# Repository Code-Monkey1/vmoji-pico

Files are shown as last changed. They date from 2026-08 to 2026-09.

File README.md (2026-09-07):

# vmoji-pico
Volumetric Display for the Raspberry Pi Pico (RP2040).

Mechanical CAD (OpenSCAD dual-motor drive): [3D/README.md](3D/README.md).

## Firmware host tests

Logic tests run on the PC (no Pico SDK / board required):

```bash
cmake -S tests/firmware -B build-host-tests
cmake --build build-host-tests
ctest --test-dir build-host-tests --output-on-failure
```

Manual sim/POV bring-up steps: [tests/firmware/acceptance/BRINGUP.md](tests/firmware/acceptance/BRINGUP.md).

## Telemetry dashboard

The firmware streams binary telemetry at 10 Hz - measured scan rate, per-scan
jitter, die temperature and the live framebuffer - to a PySide6 desktop
dashboard that plots it in real time, logs it, and can replay a recording.

See [tools/dashboard/README.md](tools/dashboard/README.md).

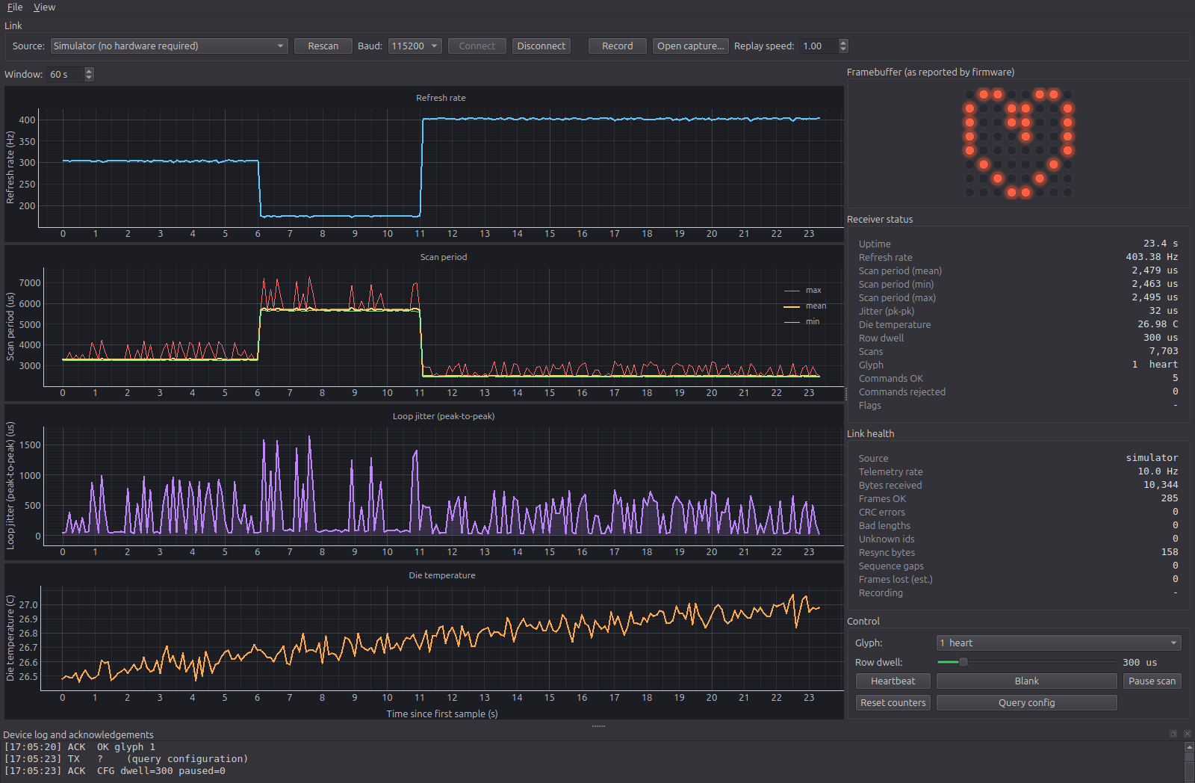
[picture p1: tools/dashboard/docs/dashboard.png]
vmoji telemetry dashboard


The dashboard also runs against a built-in simulator, so no hardware is needed to
try it:

```bash
cd tools/dashboard
python3 -m venv .venv && .venv/bin/pip install -r requirements.txt
.venv/bin/python app.py
```

## Dev Env Setup

We use the "Raspberry Pi Pico Project" extension in VS Code with a Linux PC.  
With it, you can prepare the environment (install the "pico-sdk" SDK locally).  

This [PDF guide](https://pip-assets.raspberrypi.com/categories/610-raspberry-pi-pico/documents/RP-008276-DS-1-getting-started-with-pico.pdf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) explains very well what to do.

To let it run properly the commands it needs without any permission issue (without needing to always write `sudo`),
the `/etc/udev/rules.d/99-picotool.rules` file was created with the following content:
`SUBSYSTEM=="usb", ATTR{idVendor}=="2e8a", MODE="0666"`  

After, reload the rules:  
`sudo udevadm control --reload-rules`  
`sudo udevadm trigger`  

For cross-debugging, make sure you installed the appropriate tools:

`sudo apt update`  
`sudo apt install gdb-multiarch binutils-multiarch gcc-arm-none-eabi`  

## Quick Start (VS Code)

### Building
From the extension, you can click "Compile Project".  

### Flashing by Copy/Paste
If not in bootloader mode already, reconnect the Raspberry Pi Pico while pressing down on the bootloader button.  
You should now see it as a "USB device" in your file explorer.  
Copy/paste the build .uf2 output file into that USB device to flash the device.

The device will restart automatically and run the program you flashed.

### Flashing via SWD
Using the debug probe, you can flash quickly via SWD. See the guide for detailed instructions.  
This way you don't need to unplug and re-plug the raspberry pi each time, which is convenient.

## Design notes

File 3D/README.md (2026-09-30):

# vmoji mechanical (OpenSCAD) — v2

Coil-safe dual-motor gear drive for the volumetric display. The rotor turns on
**two 608ZZ**: the bottom one clamped on an M8 stud in the base, the top one hanging
under the TX deck, `vm_top_bearing_coil_clear` (10 mm) below the TX coil. A printed
plastic rotor runs through the TX–RX gap. Preview the full stack with
[`assembly-preview.scad`](assembly-preview.scad) (F5; optional Animate, `section` toggle)
and check it with [`check-collisions.sh`](check-collisions.sh).

Defaults live in [`vmoji-mech-params.scad`](vmoji-mech-params.scad). Every
print file includes that before `motor-base-common.scad`.

## BOM

| Qty | Part | Notes |
|-----|---|---|
| 2 | 608ZZ bearing | Bottom (base pocket) + top (TX deck hanging pocket). |
| 1 | M8×25 DIN 912 / ISO 4762 SHCS | Stud through the bottom 608. Head Ø13 × 8 mm, hex key 6 mm. |
| 1 | M8 hex nut | Clamps the bottom 608 inner race; the rotor's hex socket drops over it. |
| 2 | Printed race spacers | `bearing-spacer.scad`, 100 % infill. Head and nut are wider than the inner race; spacers keep them off the shields. |
| 8 | M3×6 heat-set inserts (Ø4.2) | 4 column spigots (TX deck bolts) + 4 lid posts. |
| 4 | M3×4 heat-set inserts (Ø4.2) | Rotor head PCB bosses. |
| 4 | M3×8 screws | TX deck → columns. |
| 4 | M3×8 screws | Lid → posts. |
| 4 | M3×6 screws | PCB → head. |
| 1 | M3×10 SHCS | Head center screw, self-taps into the shaft top. |
| 0–6 | M3 nuts | Counterweights (glued into the head pockets). |
| 2 | RF-300C-class motors | Ø24 × 12, Ø2.0 shaft sticking out 4–5 mm (`vm_motor_shaft_len`). |
| 1 | IR LED + 1 phototransistor | 5 mm by default (`vm_ir_d`, `vm_ir_flange_d`, `vm_ir_len` for 3 mm parts). |
| 1 | 40 × 60 mm proto PCB | 4 M3 corner holes; set `vm_pcb_hole_dx/dy` to your board (placeholder 52 × 32). |

**Buy the stud screw:** [M8 hex-socket assortment (16/20/25/30)](https://www.amazon.ca/gp/product/B0GPXBPR31).
Use a **25 mm** screw: its tip sticks ~8 mm above the nut and centers the rotor.

These SHCS are typically fully threaded. The thread crest sits inside the 608 bore;
that's fine because the inner race is clamped by the stud, not sliding on it.

## Coil-safe rules

- Face gap TX top → RX bottom: **8–20 mm** (`vm_coil_gap`, prefer 8).
- The M8 stud tip stays below the TX deck (`vm_assert_coil_gap_metal_free`).
- The top 608 stays `vm_top_bearing_coil_clear` below the TX coil (default 10 mm, hard floor 4 mm).
- No set-screw into the plastic rotor, no threads in plastic under load (hex + key drives).

World **z=0** is the structural floor / bottom 608 bottom. Table contact is at
`-vm_skirt_h` (~10.5 mm) so the SHCS head sits above the table without feet.

## Spin direction and gears

Single helical 14T / 28T, m1.25, 25°. Herringbone can't be meshed by dropping the rotor in;
helical can (the unpowered pinions turn as the teeth slide in). Mating helical gears need
**opposite** helix angles (the v1 files used the same sign for both).

`vm_rotor_dir = -1`: the rotor spins **clockwise viewed from the top**, the pinions
counter-clockwise. The hands are chosen so the pinions are pushed **down** toward the
motors (keeps the press-fits seated) and the rotor slightly up (far less than its weight).
If the rotor spins the other way, swap the motor leads (both motors in parallel, same
polarity). If you'd rather have CCW, set `vm_rotor_dir = 1` and reprint pinions + rotor.

## Material (PLA)

Everything prints in PLA. PLA softens around 55–60 °C and creeps under constant load, so:

- Don't run the motors hot; a warm can slowly loosens the pinion press-fit and crush ribs.
  If a pinion slips, put a drop of **CA glue** (cyanoacrylate, "super glue") on the shaft and press it back on.
- Keep the TX coil power reasonable; the deck holds the top 608 pocket right under it.
- Race spacers: 100 % infill. Tighten the M8 stud firmly but don't crank it.

## Print orientation

| Part | File | Orientation / tips |
|---|---|---|
| Motor base | `motor-base.scad` | Skirt down on bed. Supports from the build plate inside the skirt (floor + well ledges bridge the hollow). |
| TX deck | `motor-tx-deck.scad` | **Upside down** (coil face on bed): no overhangs, the bearing pocket opens upward. |
| Rotor shaft | `rotor-shaft.scad` | Gear face down, axis vertical. Brim; 4+ perimeters (thin shaft). |
| Rotor head | `rotor-head.scad` | Underside (RX coil rebate) on bed. |
| Pinions (×2) | `motor-pinion.scad` | Underside down; good cooling. |
| Lid | `motor-base-lid.scad` | Top face on bed (lip up). |
| Race spacers (×2) | `bearing-spacer.scad` | Flat, 100 % infill. |
| Fit coupons | `fit-test.scad` | Flat. Pick one with `coupon`, or `all`. |

## Assembly order

Every step is top-down.

1. Print the fit coupons first and tune (see **Fit tuning**).
2. Heat-set the inserts while the parts are bare: M3×6 into the 4 column spigots and the
   4 lid posts, M3×4 into the 4 head bosses (the iron clearance above each is checked).
3. **Bottom stud:** press a 608 into the base pocket (outer race on the z=0 lip). From below:
   spacer, then M8×25 up through the bearing. On top: spacer, then the M8 nut. Tighten (6 mm key
   below, 13 mm wrench above). The stud + nut must now spin freely with the inner race.
4. **Motors:** solder leads, thread them down through the well ledge hole into the skirt and
   up through the box floor slots. Press each motor into its crush-rib well until it sits on the ledge.
5. **Pinions:** put a 0.5 mm shim (`vm_pinion_face_gap`, e.g. two business cards) on the motor
   face and press the pinion down onto it; the ledge takes the force. Remove the shim.
6. **Rotor:** lower it onto the stud. The tip enters the centering bore, the hex socket drops
   over the nut (turn slightly), and the helical teeth twist into mesh with the pinions.
7. **TX deck:** glue the TX coil into the rebate (leads in the groove toward the box), push the
   IR LED in from below (flange against the step, dab of glue), and press the top 608 into the
   hanging pocket from below until it stops on the lip.
8. Lower the deck over the rotor: the bearing slides onto the journal and the column spigots
   drop into the deck recesses. Bolt it down with 4× M3×8. Route TX + IR leads into the box
   through the notch at the top of its wall.
9. **Head:** hot-glue the RX coil into the rebate (glue into the three notches), leads up
   through the lead hole. Drop the phototransistor into its hole from above (dome down,
   flange on the boss).
10. Slide the head onto the double-D key and drive the M3×10 center screw (self-taps; snug only).
11. Bolt the PCB with 4× M3×6; solder the RX leads and the phototransistor.
12. Screw the lid on (4× M3×8).
13. Balance (below).

## Balancing

The LED matrix sits off-axis, so the rotor is heavy on one side. At ~1000 RPM a few grams
off-center shakes the whole thing.

1. Take the base off the table and lay it on its side (rotor axis horizontal). Unpowered.
2. Let the rotor come to rest; the heavy side ends up at the bottom.
3. Glue M3 nuts into the head pockets on the **top** (light) side. Repeat until the rotor stays
   wherever you leave it.
4. Spin up slowly and feel for vibration; nudge weights if needed.

## Fit tuning

Print `fit-test.scad`, try each coupon on the real part, then copy the winner here.

| Param | Default | Coupon | Role |
|---|---|---|---|
| `vm_motor_shaft_d` | 1.9 | `motor_shaft` | Pinion press bore on the Ø2 shaft (proven; change only if needed). |
| `vm_top_journal_d` | 7.95 | `journal` | Journal: snug slide into the top 608 inner race. |
| `vm_bearing_fit` | 0.15 | `bearing_od` | 608 OD pockets (plus `$slop`). |
| `vm_nut_socket_extra` | 0.4 | `nut_socket` | Hex socket over the M8 nut (loose: drive only). |
| `vm_tip_bore_extra` | 0.15 | `tip_bore` | Snug bore on the M8 tip (this centers the rotor). |
| `vm_key_fit` | 0.25 | `key` | Head socket on the double-D key. |
| `vm_well_rib_interf` | 0.15 | `well` | Crush-rib grip on the motor can. |
| `vm_insert_hole_d` | 4.0 | `insert` | Heat-set pilot (plus `$slop`). |
| `vm_locate_fit` / `vm_locate_loose` | 0.15 / 0.8 | `locate` | Deck recesses on the column spigots (diagonal pair tight). |
| `vm_ir_hole_extra` | 0.3 | `ir` | IR LED / phototransistor holes. |
| `$slop` | 0.2 | — | Global print clearance (clearance holes). |

The display ghost in the preview (60×40 PCB + 8×8 matrix) is approximate; the swept
volume check uses its envelope.

## Collision and assembly checks

- **Analytic asserts** (`vm_assert_layout()` in `motor-base-common.scad`) run in every file:
  box ↔ deck gap (`vm_porch_gap`, 3 mm), coil gaps, bearing-to-coil distance, metal below the
  coil zone, well ↔ bearing walls, gear ↔ column / well clearance, IR beam gap, insert boss walls, and more.
- **Geometric checks:** `./check-collisions.sh` intersects every part pair as assembled
  (spinning parts as swept envelopes) plus a soldering-iron cylinder above every insert, and
  fails on any real overlap. Takes ~5 min on OpenSCAD 2021; newer builds are faster with
  `OPENSCAD_ARGS="--enable=manifold"`. Run a subset with `./check-collisions.sh base_deck coils`.

## File map

| File | Role |
|---|---|
| `vmoji-mech-params.scad` | Shared dims, Z stack |
| `motor-base-common.scad` | Clearances, gear math, layout, envelopes, `vm_assert_layout()` |
| `vmoji-assembly.scad` | World placement of every part + hardware ghosts |
| `assembly-preview.scad` | Full F5 assembly + animation + section |
| `collision-check.scad` / `check-collisions.sh` | Pairwise collision + iron-access checks |
| `motor-base.scad` | Floor, skirt, bottom 608 pocket, crush-rib wells, columns, box |
| `motor-base-lid.scad` | Box lid |
| `motor-tx-deck.scad` | TX plate + hanging top 608 pocket + IR emitter |
| `motor-pinion.scad` | 14T helical, press-fit |
| `rotor-shaft.scad` | Rotor: 28T helical gear + nut socket + journal + key |
| `rotor-head.scad` | RX coil holder + PCB mount + counterweights + IR receiver |
| `bearing-spacer.scad` | 608 inner-race spacer |
| `fit-test.scad` | Fit coupons |
| `archive/` | v1 parts (driven shaft/gear, shaft collar, collets). Kept for reference; their includes no longer resolve from that folder. |

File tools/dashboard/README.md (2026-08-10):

# vmoji telemetry dashboard

A real-time instrumentation dashboard for the vmoji volumetric display, built to
debug the RP2040 firmware's scan loop from a PC over USB or UART.

The dashboard streaming from the simulator

The screenshot shows a live session. The two steps in the refresh-rate trace are
row-dwell changes sent from the control panel: raising the dwell from 400 us to
700 us drops the scan rate from ~400 Hz to ~190 Hz, and the scan-period trace
moves inversely. That correlation is the entire point of the tool - it turns "the
display looks dim" into a number you can act on.

## Why this exists

The display is a real-time system. An 8x8 matrix multiplexed one row at a time
only looks like an image because the scan loop is fast and *regular*; if the loop
loses time to command handling or a slow serial write, the result is visible
flicker and uneven brightness. None of that is diagnosable from the firmware
side, because the act of printing debug output is itself the thing that perturbs
the timing.

So the firmware measures its own scan interval, accumulates min/mean/max over a
100 ms window, and ships that as a compact binary frame. The host does the
plotting, the storage and the interpretation.

## Architecture

```
 ┌─────────────┐
 │ SerialSource│──┐
 │ SimSource   │──┼──▶ ReaderWorker ──queued signal──▶ TelemetryModel
 │ ReplaySource│──┘   (on a QThread)                  (bounded deques)
 └─────────────┘            │                               │
                            ▼                    QTimer @ 30 Hz
                      CaptureWriter                         │
                       (.vmc file) ─────────────────────▶  views
                                    replay
```

Four decisions carry the design:

**The reader thread never touches a widget.** `ReaderWorker` is a plain `QObject`
moved onto a `QThread`. It owns the source and the parser, and it communicates
only by emitting signals. Because the connections are made from the GUI thread,
Qt delivers them as queued connections and marshals the payload onto the event
loop. Blocking reads stay off the event loop, so the UI never freezes, and there
is not a single explicit lock in the GUI path.

**The data rate and the frame rate are independent.** Messages are appended to
the model on arrival; a `QTimer` repaints at 30 Hz regardless. Nobody can see
faster than that, and coupling repaints to arrivals is the standard way these
tools fall over when the data rate rises. The same UI would work unchanged at
10 kHz.

**Every buffer is bounded.** Series are `deque(maxlen=12000)` - 20 minutes at
10 Hz - and the log view is capped at 2000 blocks. A monitoring tool gets left
running for days, and an unbounded list is a memory leak with a good excuse.
pyqtgraph is configured with `setDownsampling(auto=True, mode='peak')` and
`setClipToView(True)`, so only the visible, decimated samples are rasterised.

**The source is swappable.** The app runs identically off a live board, a
simulator, or a recorded capture. That means it can be developed and demonstrated
with no hardware, and it means a field capture can be re-run through the exact
production parser.

## The wire protocol

Defined once, in [`../../vmoji/telemetry_frame.h`](../../vmoji/telemetry_frame.h),
and shaped after GNSS receiver binary protocols such as u-blox UBX and RTCM 3.x:

```
offset  size  field
0       2     sync word 0xAA 0x55
2       2     payload length, u16 little-endian
4       1     message id
5       1     sequence number (wraps at 256)
6       N     payload
6+N     2     CRC-16/CCITT-FALSE over offsets [2, 6+N)
```

Each element earns its place:

- **Sync word** so a listener can lock onto a stream it joined mid-frame.
- **Explicit length** so the reader knows where the message ends without escaping
  or delimiters, which is what lets the payload contain arbitrary bytes.
- **Sequence number** so the host can *detect loss it cannot prevent*. A gap is
  reported rather than silently interpolated.
- **CRC** so corrupted frames are dropped instead of plotted. It covers the length
  and id but not the sync word, so a sync word occurring inside payload data
  cannot produce a frame that also passes the CRC.

Messages: `Status` (0x01, 32-byte payload at 10 Hz), `FrameBuffer` (0x02, the 8x8
bitmap at 2 Hz), `Log` (0x03) and `Ack` (0x10), both ASCII.

`Status` carries uptime, total scan count, measured refresh rate in centi-hertz,
scan period min/mean/max, peak-to-peak jitter, RP2040 die temperature from the
on-chip sensor, accepted and rejected command counts, received byte count,
current row dwell, glyph id and status flags.

The flags are `ACTIVITY` (0x01, the activity pixel is lit), `OVERRUN` (0x02, the
UART receive ring dropped a byte), `PAUSED` (0x04, scanning suspended by
command) and `TX_DROP` (0x08, a telemetry frame was discarded because a link
could not keep up). `TX_DROP` reports a full transmit ring on the UART, or on
USB while a host is attached; bytes produced with no USB host attached are
discarded without raising it, so the flag stays meaningful on a UART-only
setup. A host that is attached but not draining its endpoint is the one gap:
the write gives up after `PICO_STDIO_USB_STDOUT_TIMEOUT_US` and the loss shows
as a gap in sequence numbers rather than as this flag.

A host that receives a `Status` payload *longer* than the 32
bytes it knows about decodes the prefix and ignores the rest, so newer firmware
can add fields without breaking an older dashboard.

### Why the uplink is ASCII

Commands stay line-oriented text (`S 2 3`, `G 4`, `D 900`, `B`, `P`, `Z`, `?`, `I`) so
the board can still be driven from `minicom` with no tooling at all during
bring-up. Framing and a CRC earn their keep on a 10 Hz downlink carrying packed
binary; they are pure overhead on six commands a minute typed by a human.

### Keeping two implementations honest

The protocol has a C++ implementation (firmware and host) and a Python one
(dashboard). Two implementations of one wire format drift apart unless something
forces them to agree, and a silent drift shows up weeks later as "the dashboard
is wrong."

So [`../protocol_selftest.cpp`](../protocol_selftest.cpp) emits reference vectors,
and `tests/test_protocol.py` pins them:

```bash
# From the repo root: the C++ side, including its own checks
g++ -std=c++17 -Wall -Wextra -I vmoji tools/protocol_selftest.cpp -o /tmp/selftest
/tmp/selftest
/tmp/selftest --vectors        # hex vectors consumed by the Python tests
```

The strongest of those tests asserts the Python encoder reproduces the C++ bytes
exactly.

## Running it

```bash
cd tools/dashboard
python3 -m venv .venv
.venv/bin/pip install -r requirements.txt

.venv/bin/python app.py                       # find a board; simulator only if none
.venv/bin/python app.py --sim                 # force the simulator
.venv/bin/python app.py --list-ports          # enumerate and rank serial ports
.venv/bin/python app.py --port /dev/ttyACM0   # a specific port, no searching
.venv/bin/python app.py --no-probe            # skip the confirm-a-frame check
.venv/bin/python app.py --replay session.vmc  # replay a capture
.venv/bin/python app.py --record out.vmc      # record from the start, no dialog
.venv/bin/python app.py --error-rate 0.05     # corrupt 5% of frames on purpose
```

### Finding the board

With no arguments the dashboard looks for real hardware and only falls back to
the simulator if there is none. Ports are ranked by USB id - the Pico's own CDC
interface (`2e8a:000a`) first, then a Debug Probe's UART bridge (`2e8a:000c`),
then anything else - and the chosen port must produce one CRC-valid frame before
the dashboard commits to it. A matching USB id only proves a Pico is plugged in,
not that it is running this firmware, so the frame is the part that counts.

The simulator is deliberately convincing, which makes it dangerous in front of an
audience. It is therefore always last in the source list, never auto-selected,
and while it is running the window wears a **SIMULATION** banner and a title-bar
marker. When a real board is connected the Link panel shows its unique chip id,
so "is this actually the hardware?" has a visible answer at all times.

If a live link drops - a bumped USB cable is the usual cause - the dashboard
reconnects on its own with a bounded backoff rather than ending the session, and
it re-scans for ports every two seconds so a board plugged in later shows up
without pressing Rescan.

### Replaying a capture

A recording is the one source you can actually navigate, so it gets a transport
bar: play/pause, restart, loop, a seek slider with elapsed and total time, and a
speed control. Seeking cuts the byte stream mid-frame and the parser
resynchronises at the new position, which is the honest outcome of seeking a
byte stream and the same recovery path a noisy link exercises.

On Linux, PySide6 6.5+ needs `libxcb-cursor0` for the xcb platform plugin:

```bash
sudo apt install libxcb-cursor0
```

### Flashing the firmware

```bash
cd vmoji
export PICO_SDK_PATH=$HOME/.pico-sdk/sdk/2.3.0
export PATH="$HOME/.pico-sdk/toolchain/14_2_Rel1/bin:$PATH"
cmake -S . -B build -G Ninja -DCMAKE_BUILD_TYPE=Release
ninja -C build
# then copy build/vmoji.uf2 onto the board in BOOTSEL mode, or flash over SWD
```

The firmware sends telemetry on **both** USB CDC (`/dev/ttyACM0`) and UART0
(GP0 TX / GP1 RX at 115200 8N1), so either transport works.

On UART the very first bytes are an unframed ASCII banner, which doubles as a
permanent test that the parser can find its sync word in a stream that does not
start with one. USB behaves differently and it is worth knowing why: the CDC
stack discards everything written before a host opens the port, so a dashboard
attaching later never sees the banner and starts mid-stream instead. Board
identity therefore travels as a framed `Log` message rather than as banner text:

```
ID vmoji 1.1.0 sha=5ab4f62a board=E6614C775B59B537
```

The firmware repeats it every 10 s and on demand via the `I` command, so it
reaches a host regardless of when that host arrived. `board=` is the RP2040's
unique chip id, which is what lets the dashboard name the specific board on
screen - and what makes a live demo distinguishable from the simulator.

### Bring-up check

Run this before opening the GUI. If something is wrong - wrong port, wrong baud,
firmware not running, TX and RX swapped - it says so in one line, instead of
leaving you staring at an empty plot unsure whether the fault is in the firmware
or the dashboard:

```bash
.venv/bin/python verify_link.py --port /dev/ttyACM0
.venv/bin/python verify_link.py --port /dev/ttyACM0 --command "D 900"
.venv/bin/python verify_link.py                       # sanity-check the simulator
```

It checks the numbers, not just that bytes moved: telemetry arriving well under
10 Hz, a zero refresh rate, an implausible die temperature, a CRC error rate over
1%, or jitter exceeding the mean scan period each produce a specific warning. It
exits non-zero on failure, so it works in a script.

### Tests

```bash
cd tools/dashboard
.venv/bin/python -m pytest tests -q
```

86 tests, no hardware required.

The protocol tests cover the cross-language vectors, frames split byte-by-byte
across reads, resynchronisation past a boot banner, CRC rejection and recovery,
oversized length fields, sequence gaps and 8-bit wrap, unknown message ids, a
sync word embedded in a payload, buffer growth under pure noise, capture
round-tripping, and `SerialSource` driven over a pty so the real pyserial path is
exercised in both directions without a board attached.

The dashboard tests cover port ranking and the probe - including a pty that
emits unrelated chatter, which must *not* be mistaken for a board - replay
seeking, pausing and speed changes, a `Status` payload carrying extra trailing
fields from hypothetical newer firmware, and the window's minimum size. That last
one is a regression guard with a specific history: the minimum had reached
986x1186, which does not fit on a 1080p laptop. A minimum size grows one
innocuous widget at a time, so the only thing that keeps it down is a test that
fails when it grows.

`tests/test_panels.py` covers the logic that was lifted out of the window:
reconnect backoff and its ceiling, the countdown text, which readout values are
highlighted, and the `exhausted` question the reader asks every source. None of
it needs an event loop.

## Repository layout

| Path | Role |
|---|---|
| `vmoji/telemetry_frame.h` | C++17 framing, `constexpr` CRC table, packed payloads. Compiles for both the Pico and the host |
| `vmoji/telemetry_flags.h` | Status flag bits, plain C, the single definition all three languages read |
| `vmoji/telemetry.h` | `extern "C"` interface so the C sources can call the C++ emitter |
| `vmoji/telemetry.cpp` | The emitter: per-scan statistics, die temperature, frame output |
| `vmoji/main.c` | `main` and the scan loop, and nothing else |
| `vmoji/matrix.c` | Pin mapping, the multiplexed scan, glyphs, digits, activity pixel |
| `vmoji/uart_link.c` | UART0 bring-up, the RX ring and its interrupt handler, boot banner |
| `vmoji/commands.c` | Line assembly and the command dispatch table |
| `tools/protocol_selftest.cpp` | Host self-test and reference vector generator |
| `tools/dashboard/protocol.py` | Parser, messages, statistics, shared constants. Qt-free |
| `tools/dashboard/sources.py` | Serial, simulator, replay sources; capture format; source factory. Qt-free |
| `tools/dashboard/model.py` | Bounded time series. Qt-free |
| `tools/dashboard/panels.py` | What each readout row says, and when it is highlighted. Qt-free |
| `tools/dashboard/reconnect.py` | Retry target and bounded backoff. Qt-free |
| `tools/dashboard/reader.py` | `QThread` worker |
| `tools/dashboard/widgets.py` | LED matrix view, key/value panel |
| `tools/dashboard/main_window.py` | Layout, wiring, repaint loop |
| `tools/dashboard/app.py` | CLI entry point |

The Qt-free boundary is deliberate: the parser, the sources, the model, the
panel formatting and the reconnect policy are plain Python and testable with
plain pytest, and the Qt layer on top is thin. The firmware is split the same
way, one job per translation unit, so the timed scan loop can be read without
the command grammar in the way.

## Things worth knowing

- **The firmware measures, the host interprets.** The device reports its observed
  scan interval, not a nominal figure from a datasheet. When the two disagree,
  the observation is what matters.
- **The observed telemetry rate is displayed alongside the firmware's reported
  refresh rate.** Two independent numbers, useful precisely when they disagree,
  because that is how you tell a firmware stall from a link problem.
- **Error counters are always visible** and highlight when non-zero. A debug tool
  that cannot tell you the link is degrading is worse than no tool, because it
  invites you to trust the plot.
- **Captures store raw bytes, not decoded records.** A decoded log can only ever
  be as correct as the parser that wrote it. Raw bytes plus host timestamps mean
  you can fix the parser and re-run history - and the CRC failures and line noise
  are preserved, which is usually the interesting part of a bad field test.
- **`--error-rate` is a feature, not a debug leftover.** Being able to *show* that
  the parser rejects corrupted frames and resynchronises is more convincing than
  asserting it.
- **Measuring timing with a blocking write changes what you measure.** The
  emitter originally pushed each frame out with `putchar_raw` per byte plus a
  blocking `uart_write_blocking`, which stalled the scan loop for longer than a
  row dwell every reporting interval. The instrument was the largest source of
  the jitter it was reporting:

  | | peak-to-peak jitter | worst scan period |
  |---|---|---|
  | blocking write | 1444 us | 4700 us |
  | queued, drained by IRQ | 57 us | 3317 us |

  Frames now go into per-link ring buffers. UART0 drains under its transmit
  interrupt; USB drains in bounded batches from the main loop, as one
  `stdio_put_string` call for the whole chunk rather than one stdio round trip
  per byte. A frame that will not fit is dropped whole rather than truncated -
  half a frame just costs the host a resync - and the drop raises a `TX DROP`
  status flag, so the gap is visible instead of silent.

## Possible next steps

- TCP source, so a board on a bench elsewhere can be monitored over the network
  (the `Source` protocol already accommodates it).
- A correlation view: dwell setting against achieved rate and jitter.
- CSV/Parquet export of the decoded series for offline analysis.
- PyInstaller packaging with a GitHub Actions matrix over Windows and Linux.
- Move the parser hot loop into C++ via pybind11 if the frame rate ever justifies
  it, reusing `telemetry_frame.h` so there is still one definition of the format.

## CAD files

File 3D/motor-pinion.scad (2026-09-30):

// Motor pinion — single helical, plain press-fit on the Ø2 motor shaft (no slit clamp).
// Blind bore: the shaft is only ~4–5 mm long; the gear sits vm_pinion_face_gap above the
// motor face (press down onto a shim of that thickness). Underside relieved for the motor
// boss. Print underside down. If a pinion ever slips, a drop of CA glue fixes it.
include <BOSL2/std.scad>
include <BOSL2/screws.scad>
include <BOSL2/gears.scad>
include <vmoji-mech-params.scad>
include <motor-base-common.scad>


/* [Press-fit] */
// Bore extra depth past the shaft tip (shaft must not bottom out).
bore_extra_depth = 0.4; // [0:0.1:2]
boss_relief_extra = 0.6; // [0:0.1:2]


/* [Hidden] */
$fa = 2;
$fs = 0.25;
$slop = 0.2;
cut_overlap = 0.2;


module motor_pinion(
    shaft_d = vm_motor_shaft_d,
    shaft_len = vm_motor_shaft_len,
    face_gap = vm_pinion_face_gap,
    gear_thickness = vm_gear_thickness,
    bore_extra_depth = bore_extra_depth,
    boss_relief_extra = boss_relief_extra
) {
    eps = cut_overlap;
    bore_depth = shaft_len - face_gap + bore_extra_depth;
    relief_h = max(0, vm_motor_boss_h - face_gap) + 0.3;

    assert(bore_depth < gear_thickness - 1, "Pinion bore breaks through the top");
    assert(vm_motor_boss_d + boss_relief_extra < mb_gear_root_d(vm_pinion_teeth) - 2,
        "Motor boss relief too wide for the pinion root");

    // Local z=0 = pinion underside (world vm_gear_z0()).
    diff() {
        up(gear_thickness / 2)
            mb_helical_gear(
                teeth = vm_pinion_teeth,
                helical = vm_pinion_helical(),
                thickness = gear_thickness
            );

        tag("remove") {
            down(eps)
                cyl(d = shaft_d, h = bore_depth + eps, anchor = BOTTOM, chamfer1 = -0.3);
            down(eps)
                cyl(d = vm_motor_boss_d + boss_relief_extra, h = relief_h + eps, anchor = BOTTOM);
        }
    }
}


motor_pinion();

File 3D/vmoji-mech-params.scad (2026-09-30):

// Single source of mechanical defaults for the dual-motor gear drive (v2).
// Include this BEFORE motor-base-common.scad in every print / preview file.
//
// BOM (coil-safe):
//   - 2x 608ZZ: bottom one in the base (on the M8 stud), top one hanging under the TX deck,
//     kept vm_top_bearing_coil_clear below the TX coil.
//   - 1x M8x25 DIN 912 / ISO 4762 socket head cap screw + 1x M8 hex nut + 2x printed
//     race spacers (bearing-spacer.scad). The screw + nut clamp the bottom 608 inner race and
//     form a stud; the rotor's hex socket slips over the nut and its bore centers on the tip.
//   - M3 heat-set inserts (Ø4.2): M3x6 in column tops and lid posts, M3x4 in the rotor head.
//   - Printed plastic rotor (rotor-shaft.scad + rotor-head.scad) through the TX–RX gap.
//
// Buy: Amazon "M8 hex socket screw assortment" (16/20/25/30). Use a 25 mm screw for the stud.
// Kit head is Ø13 x 8 mm, hex key 6 mm. These SHCS are typically fully threaded — the thread
// crest runs inside the 608 bore; that is fine because the inner race is clamped, not sliding.
//
// Fit convention: `$slop` (global print clearance) is added to clearance holes. Press / snug
// fits use explicit absolute extras below (tune them with fit-test.scad, not $slop).

/* ---- Motor (RF-300C-class) ---- */
vm_motor_d = 24;
vm_motor_h = 12;
vm_motor_shaft_d = 1.9; // Proven pinion press-fit bore on the Ø2.0 shaft; do not change casually.
vm_motor_shaft_len = 4.5; // Shaft length above the motor face (measured 4–5 mm).
// Front bearing boss on the motor face; the pinion underside is relieved around it.
vm_motor_boss_d = 7;
vm_motor_boss_h = 1;
// Terminal tabs + wires exit the can bottom through this hole in the well ledge.
vm_motor_term_hole_d = 18;

/* ---- Crush-rib press-fit motor wells (no clamp screw) ---- */
vm_well_clear = 0.3; // Radial clearance between can and smooth bore.
vm_well_rib_n = 6;
vm_well_rib_w = 1.2;
vm_well_rib_interf = 0.15; // Radial interference of each rib tip on the can.
vm_well_wall = 2.5;
vm_well_ledge_h = 1.5; // Floor ring under the can.
vm_well_rim_drop = 1.5; // Well rim sits this far below the can top.
vm_well_leadin = 0.8; // Chamfer at the rim for easy insertion.

/* ---- Gear train (2:1 single helical) ---- */
// Herringbone cannot be meshed by axial assembly; single helical can (the unpowered
// pinions rotate while the rotor drops in). Axial thrust is negligible at these torques.
vm_gear_mod = 1.25;
vm_pinion_teeth = 14;
vm_driven_teeth = 28;
vm_gear_helical = 25; // Magnitude only; hands are derived from vm_rotor_dir below.
vm_gear_backlash = 0.3;
vm_gear_thickness = 8; // Face width (pinion only grips the 4–5 mm motor shaft).
vm_gear_pressure_angle = 20;
vm_gear_slices = 8;
// Air gap between pinion underside and motor face (press the pinion down onto a shim).
vm_pinion_face_gap = 0.5;
// Rotor spin: -1 = clockwise viewed from the top, +1 = counter-clockwise.
// Hands are picked so the helix pushes the rotor UP (well below its weight) and the
// pinions DOWN toward the motors, which keeps the pinion press-fits seated.
vm_rotor_dir = -1; // [-1, 1]
function vm_driven_helical() = vm_rotor_dir * vm_gear_helical;
function vm_pinion_helical() = -vm_driven_helical();

/* ---- 608ZZ (bottom in base + top under TX deck) ---- */
vm_bearing_id = 8;
vm_bearing_od = 22;
vm_bearing_h = 7;
vm_bearing_fit = 0.15;
vm_bearing_inner_race_od = 12; // Nothing clamped/rotating may touch the shields outside this.
// OD lip at z=0: outer race sits on the annulus; spacer + head pass through the hole.
vm_bearing_lip_id = 16.8;
// Top 608: lip above the outer race only (inner race + shaft pass through).
vm_top_bearing_lip_id = 19.5;
// Steel top bearing top face → TX coil bottom face. Hard floor asserted at 4 mm.
vm_top_bearing_coil_clear = 10; // [4:0.5:20]

/* ---- M8 stud (SHCS + race spacers + nut) ---- */
// DIN 912 / ISO 4762 M8: head Ø13 x 8. ISO 4032 M8 nut: 13 AF x 6.5.
vm_shcs_d = 8;
vm_shcs_len = 25;
vm_shcs_head_d = 13;
vm_shcs_head_h = 8;
vm_bolt_head_pocket_d = 14.5; // head + print clearance
vm_nut_af = 13;
vm_nut_h = 6.5;
// Printed spacer rings touch only the inner race (head and nut are wider than it).
vm_race_spacer_id = 8.4;
vm_race_spacer_od = 11.5;
vm_race_spacer_h = 1.5;
// Continuous printed skirt so the head sits above the table (no rubber feet).
// head 8 + spacer 1.5 + ~1 clearance under head.
vm_skirt_h = 10.5;
vm_skirt_wall = 3;

/* ---- Rotor shaft (plastic, integrated driven gear) ---- */
vm_rotor_bottom_gap = 0.5; // Rotor underside above the upper race spacer.
vm_nut_socket_extra = 0.4; // Across-flats clearance: hex only drives, it does not center.
vm_tip_bore_extra = 0.15; // Snug bore on the M8 tip crest: this centers the rotor.
vm_tip_bore_headroom = 0.5; // Above the screw tip.
vm_rotor_collar_d = 11; // Shoulder above the gear; < inner race OD so it never touches shields.
vm_rotor_collar_gap = 0.5; // Collar top → top 608 inner race (rotor captive, not over-constrained).
vm_top_journal_d = 7.95; // Snug slide into the top 608 inner race (tune with fit-test.scad).
vm_rotor_shaft_d = 7.7; // Above the journal: lets the top 608 slide down freely.
// Double-D key at the shaft top for the rotor head (plus one center M3 self-tapped).
vm_key_flat = 6.2; // Across flats.
vm_key_len = 7; // Socket depth in the head.
vm_key_fit = 0.25; // Diametral clearance of the head socket on the key.
vm_center_pilot_d = 2.5; // M3 self-tap pilot in the shaft top.
vm_center_pilot_depth = 10;

/* ---- Induction rings ---- */
vm_ring_id = 21.5;
vm_ring_od = 41;
vm_ring_h = 1.2;
vm_ring_fit = 0.6; // Diametral clearance of the ring rebates.
// Face-to-face air gap between TX top and RX bottom. Hardware needs 8–20 mm; prefer 8.
vm_coil_gap = 8; // [8:0.5:20]

/* ---- TX deck ---- */
vm_deck_plate_t = 3; // Plastic under the TX ring.
vm_ring_rebate_extra = 0.3; // Rebate depth beyond ring_h.
vm_deck_shaft_clear_d = 10;
vm_deck_boss_wall = 2.5; // Around the top 608 pocket.
vm_tx_wire_y = -12; // TX lead groove runs to the +X edge at this Y.
vm_tx_wire_w = 3;

/* ---- Rotor head (RX coil + PCB) ---- */
vm_rx_recess = 0.2; // RX copper face sits this far inside the head underside.
vm_head_over_coil = 3; // Plastic above the RX coil.
// The PCB-footprint plate runs from the head underside to the disk top (prints flat).
vm_head_hub_d = 14;
vm_head_ceiling_t = 1.5; // Socket ceiling under the center screw head.
vm_center_screw_head_h = 3; // M3 SHCS head sits on the hub, under the PCB.
vm_rx_wire_d = 3.5;
vm_rx_wire_angle = 90;
vm_glue_notch_n = 3;
vm_glue_notch_w = 3;
vm_glue_notch_d = 1.5;
// Counterweight pockets (M3 nuts, glued) to balance the off-axis LED matrix.
vm_cw_n = 6;
vm_cw_r = 15;
vm_cw_nut_af = 5.5;
vm_cw_depth = 2.5;
vm_cw_fit = 0.3;

/* ---- Spinning display / PCB ---- */
// 40x60 mm proto board, 4x M3 corner holes. Hole rectangle is a placeholder: measure yours.
vm_display_pcb_x = 60;
vm_display_pcb_y = 40;
vm_display_pcb_t = 1.6;
vm_pcb_hole_dx = 52;
vm_pcb_hole_dy = 32;
vm_pcb_corner_r = 2;
vm_led_n = 8;
vm_led_pitch = 4; // 8×4 = 32 mm square matrix, standing in Z
vm_led_xy = 3.2;
vm_led_h = 1.8; // LED depth along the viewing axis (faces +Y)

/* ---- IR index sensor (firmware GP3, once per rev) ---- */
// Emitter (IR LED) in the deck facing up; receiver (phototransistor) in the head facing down.
// The emitter angle defines display angle zero.
vm_ir_d = 5; // [3, 5]
vm_ir_flange_d = 5.8; // 3 mm parts: ~3.8
vm_ir_flange_h = 1;
vm_ir_len = 8.6; // Flange bottom → dome tip. 3 mm parts: ~5.3
vm_ir_hole_extra = 0.3;
vm_ir_r = 27;
vm_ir_angle = 0;
vm_ir_tx_protrude = 1.5; // Emitter dome above the deck top.
vm_ir_rx_seat_z = 7.5; // Head-local Z of the receiver flange seat (dome just below the underside).
vm_ir_min_gap = 2;

/* ---- Base / deck layout ---- */
vm_floor_h = 5;
vm_wall_t = 3;
vm_deck_margin = 4;
vm_porch_inner_x = 50;
vm_porch_inner_y = 72;
vm_porch_inner_z = 32;
vm_porch_gap = 3; // Electronics box wall ↔ TX deck edge (lid stays removable).
vm_post_d = 9; // Lid posts (insert bosses).
vm_lid_t = 2.5;
vm_col_d = 12;

/* ---- Heat-set inserts (M3, Ø4.2) ---- */
// Brass inserts want metal M3 screws. Pilot = vm_insert_hole_d + 2*$slop (proven with yours).
vm_insert_od = 4.2;
vm_insert_hole_d = 4.0;
vm_insert_len_col = 6; // Column tops and lid posts.
vm_insert_len_head = 4; // Rotor head PCB bosses.
vm_insert_depth_extra = 1; // Pilot deeper than the insert.
vm_insert_min_wall = 2; // Boss OD >= pilot + 2 * wall.
// Free vertical cylinder above every insert at install time (soldering-iron access).
vm_iron_clear_d = 14;
vm_iron_clear_h = 20;
function vm_insert_pilot_d() = vm_insert_hole_d + 2 * $slop;
function vm_insert_depth(len) = len + vm_insert_depth_extra;
function vm_insert_boss_min_d() = vm_insert_pilot_d() + 2 * vm_insert_min_wall;
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

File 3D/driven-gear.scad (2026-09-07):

// Driven herringbone gear — slit-clamp on plastic Ø8 shaft; seats on shaft flange.
// No set-screw into plastic (avoids crushing the dielectric shaft).
include <BOSL2/std.scad>
include <BOSL2/screws.scad>
include <BOSL2/gears.scad>
include <vmoji-mech-params.scad>
include <motor-base-common.scad>


/* [Clamp] */
slit_width = 0.6; // [0.2:0.05:2]
clamp_screw = "M3";
clamp_offset = 7.2; // [4:0.1:16]
nut_trap_depth = 3.2; // [2:0.1:8]
teardrop_clamp_hole = true; // [true, false]
min_bore_to_clamp = 1.0; // [0.3:0.1:3]
hub_od = 18; // [12:0.5:40]


/* [Hidden] */
$fa = 2;
$fs = 0.25;
$slop = 0.2;
cut_overlap = 0.2;


module driven_gear(
    shaft_d = vm_shaft_d,
    bore_extra = vm_shaft_bore_extra,
    gear_mod = vm_gear_mod,
    driven_teeth = vm_driven_teeth,
    gear_helical = vm_gear_helical,
    gear_backlash = vm_gear_backlash,
    gear_thickness = vm_gear_thickness,
    gear_pressure_angle = vm_gear_pressure_angle,
    gear_slices = vm_gear_slices,
    hub_h = vm_driven_hub_h,
    hub_od = hub_od,
    slit_width = slit_width,
    clamp_screw = clamp_screw,
    clamp_offset = clamp_offset,
    nut_trap_depth = nut_trap_depth,
    teardrop_clamp_hole = teardrop_clamp_hole,
    min_bore_to_clamp = min_bore_to_clamp
) {
    eps = cut_overlap;
    bore_d = shaft_d + bore_extra + 2 * $slop;
    screw_d = struct_val(screw_info(clamp_screw), "diameter");
    root_d = 2 * root_radius(
        mod = gear_mod,
        teeth = driven_teeth,
        helical = gear_helical,
        pressure_angle = gear_pressure_angle,
        backlash = gear_backlash
    );
    hub_d = min(hub_od, root_d - 1.5);
    r = hub_d / 2;
    jaw_half = sqrt(max(0.01, r * r - clamp_offset * clamp_offset));
    clamp_hole_l = 2 * jaw_half + 2;
    total_h = gear_thickness + hub_h;
    outer_d = mb_gear_outer_d(driven_teeth, gear_mod, gear_helical, gear_pressure_angle);
    slit_d = max(hub_d, outer_d) + 1;

    assert(hub_d > bore_d + 2 * min_bore_to_clamp + screw_d,
        "hub_od too small for clamp");
    assert(clamp_offset + screw_d / 2 < r,
        "clamp_offset places the screw outside the hub");
    assert(clamp_offset - screw_d / 2 > bore_d / 2 + min_bore_to_clamp,
        "clamp_offset is too close to the shaft bore");

    // Local z=0 = gear bottom (seats on driven-shaft flange top).
    diff() {
        union() {
            up(gear_thickness / 2)
                mb_herringbone_gear(
                    teeth = driven_teeth,
                    thickness = gear_thickness,
                    mod = gear_mod,
                    helical = gear_helical,
                    backlash = gear_backlash,
                    pressure_angle = gear_pressure_angle,
                    shaft_diam = 0,
                    slices = gear_slices
                );

            up(gear_thickness)
                cyl(d = hub_d, h = hub_h, anchor = BOTTOM);
        }

        tag("remove") {
            down(eps / 2)
                cyl(d = bore_d, h = total_h + eps, anchor = BOTTOM);

            down(eps / 2)
                left(eps)
                    cuboid(
                        [slit_d / 2 + eps, slit_width, total_h + eps],
                        anchor = LEFT + BOTTOM
                    );

            up(gear_thickness + hub_h / 2)
                right(clamp_offset)
                    screw_hole(
                        clamp_screw,
                        l = clamp_hole_l,
                        teardrop = teardrop_clamp_hole,
                        orient = FWD
                    )
                        position(BOT)
                            nut_trap_inline(
                                l = nut_trap_depth + eps,
                                spec = clamp_screw,
                                anchor = BOT
                            );
        }
    }
}


driven_gear();

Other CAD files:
3D/driven-shaft.scad
3D/archive/driven-shaft.scad
3D/archive/motor-collet-left.scad
3D/archive/motor-collet-right.scad
3D/archive/motor-collet.scad
3D/archive/shaft-collar.scad
3D/assembly-preview.scad
3D/bearing-spacer.scad
3D/collision-check.scad
3D/driven-shaft_part2.scad
3D/fit-test.scad
3D/motor-base-common.scad
3D/motor-base-lid.scad
3D/motor-base.scad
3D/motor-collet-left.scad
3D/motor-collet-right.scad
3D/motor-collet.scad
3D/motor-tx-deck.scad
3D/rotor-head.scad
3D/rotor-shaft.scad
3D/shaft-collar.scad
3D/vmoji-assembly.scad

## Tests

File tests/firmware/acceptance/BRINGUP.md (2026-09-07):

# Manual bring-up acceptance (after flashing `vmoji.uf2`)

Drive the board over USB CDC (`/dev/ttyACM0`) or UART0. Line endings: `\n`.

## Knobs (firmware defaults)

| Knob | Default | Notes |
|---|---|---|
| IR GPIO | GP3 | Active-low falling edge, internal pull-up |
| IR refractory | 500 µs (`IR_REFRACTORY_US`) | Bounce shorter than this is ignored |
| Blank settle | 5 µs (`MATRIX_BLANK_SETTLE_US`) | Blank between POV mux steps |
| Sync-loss blank | 250 ms | No IR edge → display stops |

## 1. Static matrix

1. Power the Pico; open a serial terminal at 115200 (USB CDC).
2. Send `G 1` — heart glyph should appear.
3. Send `S 2 3` — score digits; activity pixel blinks.
4. Dashboard (optional): Status messages arrive; CRC errors ~0.
5. Send `P` (pause) — display freezes; board must **not** watchdog-reset.

## 2. Simulated POV (~1000 RPM)

1. Send `M sim`
2. Send `V 1` (asymmetric L)
3. Query `?` — expect `mode=sim`, `rpm` near 1000, `period` near 60000.
4. On a stationary board the matrix will flicker/glow as masks cycle; a logic
   analyzer on a column GPIO should show blank+settle then lit dwell repeating
   (~78 µs-scale steps at 1000 RPM / 768 steps).

## 3. Real IR sync (GP3)

1. Wire the IR index sensor to **GP3** (active-low / falling edge; internal pull-up).
2. Send `M pov` and `V 1`.
3. Spin the rotor (or toggle GP3 once per rev).
4. `?` should show `rpm` tracking actual speed without wild bounce from contact noise.
5. The asymmetric feature should appear locked in space, not smeared.
6. Stop the index pulses — within ~250 ms the display should blank/stop.
7. Status flag `FIFO_OVF` should stay clear under normal operation.

## 4. Regression commands

- `M static` returns to glyph mode.
- `V 0` / `V 2` switch cube / index-bar volumes in sim or pov.
- Bad input (`M nope`, `V 9`) returns `ERR …` ack.

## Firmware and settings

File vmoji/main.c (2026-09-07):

// vmoji: volumetric POV display on the RP2040.
//
// This file is only the wiring. Core 0 owns commands, telemetry, rotation sync
// and volume bake; core 1 runs the PIO-paced parallel GPIO scan. The loop below
// is deliberately short enough to read in one go — scan (or POV service), drain
// input, report, kick the watchdog — because that shape is the timing contract
// the whole instrument is built to measure.

#include <stdio.h>

#include "commands.h"
#include "hardware/watchdog.h"
#include "matrix.h"
#include "pico/stdio.h"
#include "pico/stdlib.h"
#include "pico/time.h"
#include "pio_scan.h"
#include "pov_runtime.h"
#include "rotation_sync.h"
#include "telemetry.h"
#include "uart_link.h"
#include "app_mode.h"

/* Generous next to a ~3 ms scan: long enough that a slow interval is never
 * mistaken for a hang, short enough that a real lockup recovers on its own. */
#define WATCHDOG_TIMEOUT_MS 2000

/** Bytes taken from USB per pass, so a flood cannot monopolise the loop. */
#define STDIO_DRAIN_LIMIT 128

static void drain_uart_input(void)
{
    uint8_t ch;
    while (uart_link_pop(&ch)) {
        commands_feed_byte(ch);
    }

    /* Move the interrupt handler's observations into telemetry from here, so
     * the ISR itself never reaches into the emitter. */
    bool overrun = false;
    uint32_t new_bytes = 0;
    uart_link_drain_stats(&overrun, &new_bytes);
    if (overrun) {
        telemetry_set_flag(VMOJI_FLAG_OVERRUN, true);
    }
    if (new_bytes > 0) {
        telemetry_note_rx_bytes(new_bytes);
    }
}

/** USB CDC (/dev/ttyACM0): the same command lines as UART0. */
static void drain_stdio_input(void)
{
    for (int n = 0; n < STDIO_DRAIN_LIMIT; n++) {
        int c = getchar_timeout_us(0);
        if (c == PICO_ERROR_TIMEOUT) {
            break;
        }
        if (c < 0 || c > 255) {
            continue;
        }
        telemetry_note_rx_bytes(1);
        commands_feed_byte((uint8_t)c);
    }
}

static void update_pov_telemetry(void)
{
    RotationSnapshot rot = pov_runtime_rotation();
    AppMode mode = pov_runtime_mode();
    telemetry_set_pov(rot.rpm, rot.period_us, (uint8_t)mode,
                      (uint8_t)pov_runtime_volume_id());
    telemetry_set_flag(VMOJI_FLAG_SYNC_OK, rot.sync_ok);
    telemetry_set_flag(VMOJI_FLAG_SIM, mode == APP_MODE_SIM);
}

int main(void)
{
    stdio_init_all();
    uart_link_init();

    pio_scan_init();
    matrix_init();
    rotation_sync_init();
    pov_runtime_init();
    pov_runtime_start_core1();

    telemetry_init();
    commands_init_default();
    telemetry_log("vmoji POV telemetry online");
    telemetry_send_identity();

    /* Pause while a debugger has the core halted, so single-stepping does not
     * look like a firmware hang and trigger a reset. */
    watchdog_enable(WATCHDOG_TIMEOUT_MS, true);

    while (true) {
        AppMode mode = pov_runtime_mode();

        if (!commands_scan_paused()) {
            if (mode == APP_MODE_STATIC) {
                matrix_refresh();
                telemetry_note_scan();
            } else {
                pov_runtime_service();
            }
        }

        drain_uart_input();
        drain_stdio_input();
        update_pov_telemetry();
        telemetry_set_flag(VMOJI_FLAG_ACTIVITY, matrix_activity_pending());
        telemetry_set_framebuffer(matrix_framebuffer());
        telemetry_service();
        watchdog_update();
    }
}

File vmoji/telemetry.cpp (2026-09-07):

// Telemetry emitter for the vmoji scan loop.
//
// Design constraints that shaped this file:
//
//  - The matrix scan loop is the real-time task. Nothing here may block for
//    longer than a row dwell, or the display visibly tears. So statistics are
//    accumulated with a handful of integer operations per scan and only
//    serialised once per reporting interval.
//  - No dynamic allocation and no floating point in the per-scan path.
//  - Frames go to both USB CDC and UART0, so the dashboard works whether the
//    board is on /dev/ttyACM0 or behind a TTL adapter on GP0/GP1.
//  - Emitting a frame must not block the scan loop. Both links are fed through
//    ring buffers: UART0 drains under its TX interrupt, USB drains in bounded
//    batches from the main loop. Measuring your own timing with a blocking
//    write means the measurement changes what it measures - the earlier
//    version of this file cost ~1.4 ms of peak-to-peak jitter on every
//    reporting interval, which is larger than a row dwell.

#include "telemetry.h"

#include "led-matrix.h"
#include "telemetry_frame.h"
#include "vmoji_version.h"

#include "hardware/adc.h"
#include "hardware/irq.h"
#include "hardware/sync.h"
#include "hardware/uart.h"
#include "pico/stdio.h"
#include "pico/stdio_usb.h"
#include "pico/time.h"
#include "pico/unique_id.h"

#include <cstdio>
#include <cstring>

namespace {

// Matches the UART configured in uart_link.c.
//
// This is a function rather than a `constexpr` constant because the SDK's
// `uart0` macro expands to a reinterpret_cast of a fixed peripheral address, and
// a cast from an integer to a pointer is not a constant expression. Wrapping it
// in an inline accessor keeps it free at runtime while avoiding a dynamically
// initialised global, which is worth avoiding on a microcontroller.
inline uart_inst_t *telemetry_uart() { return uart0; }

constexpr std::uint64_t kStatusIntervalUs = 100000u;      // 10 Hz
constexpr std::uint64_t kFrameBufIntervalUs = 500000u;    // 2 Hz

// Re-announced rather than sent only at boot, because a host almost always
// attaches after the board has been powered for a while - and on USB the stack
// discards anything written before the port is opened.
constexpr std::uint64_t kIdentityIntervalUs = 10000000u;  // 10 s

constexpr std::uint8_t kTempAdcInput = 4u;  // RP2040 on-die temperature sensor

// Power of two so the wrap is a mask. Sized to hold roughly a second of
// telemetry, which is far more slack than a healthy link needs and enough to
// ride out a host that stops reading for a moment.
constexpr std::size_t kTxRingSize = 1024u;
constexpr std::size_t kTxRingMask = kTxRingSize - 1u;

// How much to hand to the USB stack per pump. The main loop runs hundreds of
// times a second, so this is ample throughput while bounding the time any one
// call can spend inside the CDC write.
constexpr std::size_t kUsbChunk = 128u;

/**
 * Single-producer, single-consumer byte ring.
 *
 * The scan loop is the only producer and the drain (ISR for UART, main loop for
 * USB) is the only consumer, so the indices need no lock: each is written by
 * exactly one side and read by the other. `volatile` plus that discipline is
 * what makes this safe against an interrupt landing mid-push.
 */
class TxRing {
public:
    void reset() {
        head_ = 0;
        tail_ = 0;
    }

    std::size_t used() const {
        return (head_ - tail_) & kTxRingMask;
    }

    bool empty() const { return head_ == tail_; }

    /** All-or-nothing: a partially written frame is worse than no frame, since
     *  the host would have to resynchronise past the truncated one. */
    bool push(const std::uint8_t *data, std::size_t size) {
        if (size > (kTxRingSize - 1u) - used()) {
            return false;
        }
        std::uint32_t head = head_;
        for (std::size_t i = 0; i < size; ++i) {
            buffer_[head] = data[i];
            head = (head + 1u) & kTxRingMask;
        }
        head_ = head;  // publish only once the bytes are in place
        return true;
    }

    bool pop(std::uint8_t &out) {
        if (empty()) {
            return false;
        }
        out = buffer_[tail_];
        tail_ = (tail_ + 1u) & kTxRingMask;
        return true;
    }

private:
    std::uint8_t buffer_[kTxRingSize];
    volatile std::uint32_t head_ = 0;
    volatile std::uint32_t tail_ = 0;
};

TxRing g_uart_tx;
TxRing g_usb_tx;

struct IntervalStats {
    std::uint32_t count;
    std::uint32_t sum_us;
    std::uint16_t min_us;
    std::uint16_t max_us;

    void reset() {
        count = 0;
        sum_us = 0;
        min_us = 0xFFFFu;
        max_us = 0;
    }

    void add(std::uint32_t period_us) {
        // Clamp rather than wrap: a garbage 70000 us reading is less misleading
        // than a wrapped 4 us one, and it stays visible on the plot.
        const std::uint16_t clamped =
            period_us > 0xFFFFu ? 0xFFFFu : static_cast<std::uint16_t>(period_us);
        ++count;
        sum_us += clamped;
        if (clamped < min_us) {
            min_us = clamped;
        }
        if (clamped > max_us) {
            max_us = clamped;
        }
    }
};

struct State {
    IntervalStats interval;
    std::uint64_t last_scan_us;
    std::uint64_t last_status_us;
    std::uint64_t last_framebuf_us;
    std::uint64_t last_identity_us;
    std::uint32_t scan_count;
    std::uint32_t rx_bytes;
    std::uint16_t cmd_ok;
    std::uint16_t cmd_err;
    std::uint16_t row_dwell_us;
    std::uint8_t glyph_id;
    std::uint8_t flags;
    std::uint8_t seq;
    std::uint16_t rpm;
    std::uint8_t mode;
    std::uint8_t volume_id;
    std::uint32_t rev_period_us;
    vmoji::FrameBufferPayload framebuffer;
    std::uint16_t tx_dropped_uart;
    std::uint16_t tx_dropped_usb;
    bool temp_ready;
};

State g{};

/** Start, or restart, transmission of whatever is queued for the UART.
 *
 * The whole thing runs with interrupts off because the ISR pops from the same
 * ring and clears TXIM as it empties it; interleaving with either would leave
 * bytes in the buffer with no interrupt scheduled to move them. */
void uart_tx_kick() {
    uart_hw_t *hw = uart_get_hw(telemetry_uart());
    const std::uint32_t ints = save_and_disable_interrupts();

    // The PL011 raises TXIM as the FIFO *drains past* its trigger level, so
    // arming it on an already-empty FIFO never fires and the queue sits there
    // forever. Writing the first bytes by hand creates the level to fall from;
    // after that the ISR keeps it fed. Without this the link only came alive
    // because the boot banner happened to prime the FIFO first.
    std::uint8_t byte;
    while ((hw->fr & UART_UARTFR_TXFF_BITS) == 0u && g_uart_tx.pop(byte)) {
        hw->dr = byte;
    }
    if (!g_uart_tx.empty()) {
        hw_set_bits(&hw->imsc, UART_UARTIMSC_TXIM_BITS);
    }

    restore_interrupts(ints);
}
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

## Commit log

2026-03-30 First messy version of vmoji-pico
2026-05-11 EOL for uart print
2026-05-14 Light one LED at a time, in order
2026-08-10 Upgrade pico SDK to 2.3.0
2026-08-10 Add binary telemetry framing and a self-measuring scan loop
    The scan loop is the real-time task, so it cannot be debugged by printing
    from inside it: the printing is what perturbs the timing. Instead the
    firmware now measures its own scan interval, accumulates min/mean/max over
    a 100 ms window, and ships that as a compact binary frame alongside the
    die temperature, counters and the live framebuffer.
    The frame layout (sync word, length, id, sequence, payload, CRC-16) is
    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
2026-08-10 Add PySide6 telemetry dashboard with logging and replay
    Plots the firmware's scan rate, period spread, jitter and die temperature
    in real time, mirrors the framebuffer, and exposes the control commands.
    The reader runs as a QObject moved onto a QThread and never touches a
    widget; it emits batched signals which Qt marshals onto the GUI thread as
    queued connections. Repaints are driven by a 30 Hz QTimer rather than by
    data arrival, so the arrival rate and the frame rate are independent and
    the same UI would serve a 10 kHz link. Series are bounded deques with
    pyqtgraph downsampling and clip-to-view, because a monitoring tool gets
    left running for days.
    The byte source is swappable between liv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
2026-08-10 Add a headless bring-up check and hide legacy serial ports
    verify_link.py listens for a few seconds and reports whether valid
    telemetry is arriving, so a bring-up problem is identified before the GUI
    is opened rather than presenting as an empty plot of ambiguous cause. It
    validates the values as well as the byte flow: an implausible die
    temperature, a zero refresh rate or jitter exceeding the mean scan period
    each produce a specific warning, and it exits non-zero for use in scripts.
    Port enumeration now filters to devices with a USB vendor id, since a
    typical Linux box exposes 32 legacy /dev/ttyS* nodes that would otherwise
    bury the one port anyone wants.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
2026-08-10 Upgrade to pico SDK 2.3.0
2026-08-10 Device detection improvement in dashboard
2026-08-10 Send identity, catch line overflow errors
    [telemetry.cpp]
2026-08-10 Improve connection stability, including reconnect
    [telemetry.cpp]
2026-09-02 WIP add "hat" to shaft collar (draft)
    [shaft-collar.scad]
2026-09-02 Improve draft of "hat" (PCB mount)
    [shaft-collar.scad]
2026-09-02 Add pocket under PCB mounting holes
    [shaft-collar.scad]
2026-09-02 Adapt nut pockets
    [shaft-collar.scad]
2026-09-03 Use rectangular slit for shaft collar
    [shaft-collar.scad]
2026-09-07 Ignore .stl files
2026-09-07 WIP motor base and its pieces
    [motor-base-common.scad, motor-base-lid.json, motor-base-lid.scad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]
2026-09-07 WIP: use 2 motors in parallel (scad)
    [assembly-preview.scad, driven-gear.scad, motor-base-common.scad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]
2026-09-07 WIP 3D print no steel rod
    [assembly-preview.scad, driven-gear.scad, driven-shaft.scad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]
2026-09-07 M8x20 shank under the head
    [assembly-preview.scad, driven-shaft.scad, motor-base.scad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]
2026-09-07 Review of mechanical design, fix with skirt
    [assembly-preview.scad, driven-shaft.scad, motor-base.scad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]
2026-09-09 Set the IR pin number in the code
    I just soldered it
2026-09-16 Replace switch cutout cuboid by cyl
    [motor-base.json, motor-base.scad]
2026-09-16 vm_motor_shaft_d = 1.9
    [vmoji-mech-params.scad]
2026-09-18 Make holes in motor base go through completely
    The wire hole and the switch cutout
    [motor-base.scad]
2026-09-18 Some tuning
    [motor-base.json, motor-collet.json, motor-collet.scad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]
2026-09-18 Create individual parts for driven shaft (part 1 & 2)
    To avoid floating pieces when printing
    [driven-shaft_part1.scad, driven-shaft_part2.scad]
2026-09-30 Rotor head, no more clamp screw
    [assembly-preview.scad, bearing-spacer.scad, collision-check.scad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]
2026-10-18 Measured pcb hole distances
2026-10-21 Make the motor wells less narrow
2026-10-23 Tweak motor base cable hole
    A little bigger, a little higher to avoid conflict with switch
2026-10-30 Add power cable cradle, and show switch in preview
2026-10-30 Add X pixel command and pixel walk bring-up tool
    `X <row> <col>` clears the matrix and lights one pixel; the ack names the
    row and column GPIOs so a dim or dead LED traces straight to its joints.
    walk_pixels.py steps through all 64 LEDs, optionally recording a note per
    pixel. The simulator understands X too.
2026-10-30 Add a Pixel walk panel to the dashboard
    The walk lights each LED alone, top-left to bottom-right, and lets each one
    be scored 0-5 (buttons or digit keys) and exported to CSV with the GPIOs the
    firmware names in its X ack. The logic lives in the Qt-free pixel_walk.py;
    walk_pixels.py is now a thin headless wrapper over it.
    Running the walk on the board showed firmware row 0 is the physical top, so
    the walk order and the board_row_pins() comment are corrected. The POV
    geometry still assumes row 0 is the bottom; flagged in that comment.
2026-10-30 Fix upside-down POV volumes: content in height z, one row/z flip
    Matrix row 0 is the physical top (verified with the pixel walk), but the
    geometry adapter mapped z to rows as the identity, so z=0 landed on the
    top row. The asymmetric L also bypassed the adapter by passing z into the
    row-based volume_set(), so fixing the mapping alone would have left it
    inverted.
    geometry_row_to_z()/geometry_z_to_row() now flip, and volume_set()/
    volume_get() take height z and convert, so shape code never sees matrix
    rows. The built-in shapes keep their coordinates: they were written z-up
    all along and now render as written. Orientation tests pin it; three of
    them fail against the old code.
    BRINGUP.md gains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
2026-11-02 Increase coil groove size
    The new 5V/2A coils are slightly bigger, and need a bigger groove
2026-11-03 Do a pixel walk on boot by default
    This is so the board looks alive when you power it on.
    Syncs with the dashboard. Most dashboard commands "take the display" (it stops the pixel walk so that it can execute its own command).
2026-11-03 Create 3D/scripts folder, with export-stl.sh
    Harden collision check
2026-11-03 Decode the full 40-byte Status & guard the wire format with shared vectors
2026-11-03 Build the UART banner from the command table
2026-11-07 Pico tool automatic setup from RPi repo
